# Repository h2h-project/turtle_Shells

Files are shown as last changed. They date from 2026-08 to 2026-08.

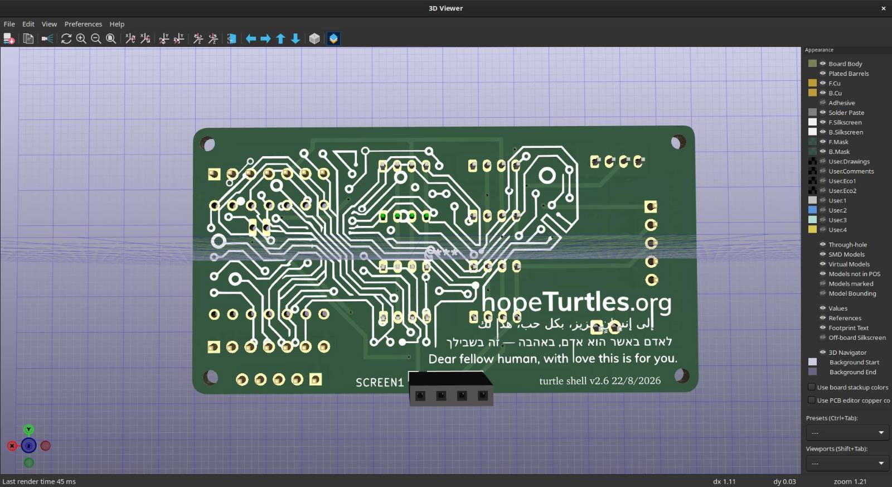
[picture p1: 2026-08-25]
photos/v2.6-back.jpg

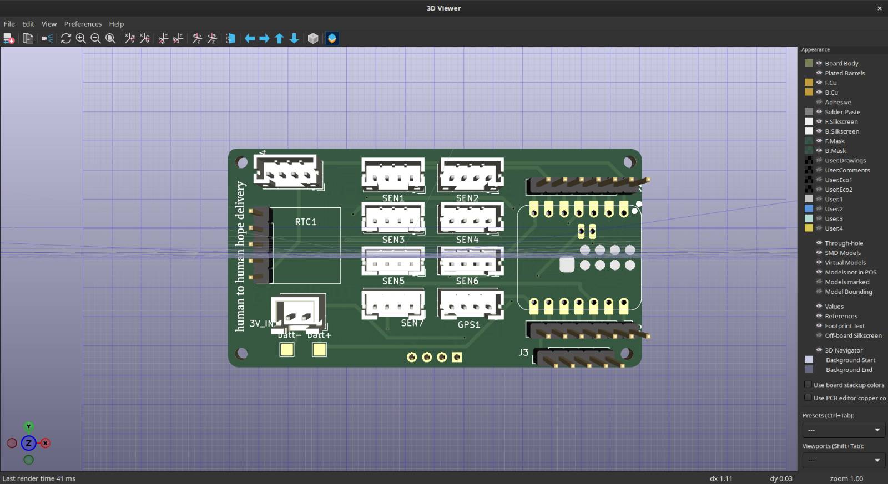
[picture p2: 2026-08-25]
photos/v2.6-front.png

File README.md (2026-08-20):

# The Hope Turtle Shell
### Our Open Source Printed Circuit Board for the Turtle Control Bottle

The Human2Human project aims to bring hope and humanity to the most hurting and isolated places on the planet — in a way that doesn't trouble the health and happiness of animals, fish and other our fellow creatures. To do so, we've developed the hope turtle: a non-capital, open-source, autonomous marine vehicle that embodies Earthen principles. This repository holds the designs for our "Turtle Shell" printed circuit board.  This is the PCB that holds of microprocessor, sensors and circuits to run our TurtleOS (https://github.com/h2h-project/turtleOS) navigation platform.  

Our vision is to create a simple and inexpensive PCB that anyone anywhere, keen to build a turtle, can put together themselves and set to sail for under 100$ using local and organic materials as much as possible.

## Philosophy

The design of our Turtle Shell PCB is shared under a CERN Open Hardware Licence Version 2 - Strongly Reciprocal.  While our CERN-OHL-S license does not legally restrict military use, we ask that anyone building on this work honor the spirit it was created in — this design exists to bring aid to isolated and vulnerable communities, not for weapons or warfare.  That's the same principle behind releasing this repository at all: any group doing resonant human/ecological work — coastal monitoring, disaster response, ocean research, humanitarian delivery — should be able to take this board, understand exactly how and why it's built the way it is, and carry it further without waiting on us or paying anyone for the privilege.

The Turtle Shell is designed from the ground up to be assembled by hand, by people who have never assembled a circuit board before. Every component on it is through-hole — there is no surface-mount soldering, no solder paste, no reflow oven, nothing that requires equipment beyond a basic iron and a steady hand. Sensors connect via inexpensive, widely-available modules and JST cables rather than being permanently fixed to the board, which keeps the parts list cheap, keeps a broken sensor a five-minute swap rather than a rework job, and keeps the barrier to building one of these low enough that a volunteer, a partner workshop, or a local maker space anywhere in the world can put one together. 

## The PCB

The current version of the Turtle Shell (v2.4) is a compact, two-layer, 70×37mm control board built around the Seeed Studio XIAO ESP32-S3.  While you don't necessarily need a Xiao ESP32-S3 to run turtle (turtleOS v2.3 has a hardware abstraction layer that supports only microprocessors), we've decided to focus our PCB development on this MP after extensively testing various alternatives.   While the Xiao ESP32-S3 is not nearly as equipped and robust as navigation specific boards, it resonates fully with our principles of open source and low-cost decentralized replicability.  The Xiao is also is a fraction of the cost-- which is crucial to our larger project goal of keeping turtle creation cost at under 100$.

The loaded turtle Shell essentially runs TurtleOS and coordinates everything the vessel does. It exposes seven generic 2.00mm JST sensor ports plus a dedicated GPS port, so the same board can carry whatever mix of instruments a given voyage needs — a magnetic angle encoder for rudder position, a combined accelerometer/gyroscope/compass/barometer for heading and weather, a current and voltage monitor for tracking the power budget, a temperature and humidity sensor to watch over the sealed enclosure's health — alongside dedicated sockets for a display and a real-time clock, breakout headers for the microcontroller's full pinout, and a servo connector kept deliberately isolated from the board's own power traces. It's a small board asked to do a lot, and every connector on it exists because a real sensor needed a reliable, correctly-oriented place to plug in.

Here's a quick list of our core components for our v.24 turtle shell:

| Component | Function | Interface | Approx. Cost (USD) |
|---|---|---|---|
| Seeed XIAO ESP32-S3 | Main microcontroller, runs TurtleOS | — | ~$7.50 |
| Xiao GPS module | Position & UTC time | UART, GPS1 port | ~$7 |
| GY-87 10DOF (MPU6050 + HMC5883L/QMC5883 + BMP180) | Heading, attitude, barometric pressure | I²C, SEN port | ~$7 |
| AS5600 | Rudder/servo angle sensing | I²C, SEN port | ~$1.50 |
| INA219 (GY-219) | Battery current, voltage & power monitoring | I²C, SEN port | ~$2 |
| AHT20 | Enclosure temperature & humidity | I²C, SEN port | ~$2.50 |
| 1.3" OLED (SH1106) | Status display | I²C, SCREEN1 socket | ~$4.50 |
| DS3231 RTC (5-pin) | Spoof-resistant, GPS-independent timekeeping | I²C, RTC1 header | ~$3.50 |
| JST↔Dupont cables (×6, mixed lengths) | Connect modules to SEN ports | — | ~$3 |
| **Subtotal** | | | **~$38** |

You can see an indepth breakdown of the Turtle hardware stack here:
https://github.com/h2h-project/turtleOS/blob/main/hardware_stack.md

## Where We're Headed

As of August 2026 we're in full development, printing and prototyping mode-- so things are evolving fast!  

The next revision is aimed at making the board more self-contained and more reliable at sea, without giving up the simplicity that makes it buildable by hand. We're working out how to bring battery power directly onto the board — using spring-loaded contacts to reach the microcontroller module's own charging circuit rather than routing through a less efficient path — alongside dedicated, correctly-keyed sockets for the current sensor and the inertial measurement unit, and a permanent home for the solar charging circuit, so fewer loose modules and wires are rattling around inside a hull that will spend weeks rolling in ocean swell. None of this is finished, and some of it may not survive contact with the next prototype — but the goal stays the same: a board that's a little more finished each time, still cheap, still imminently buildable, and still something anyone resonating with this repository and our human2human project can pick up and carry forward.

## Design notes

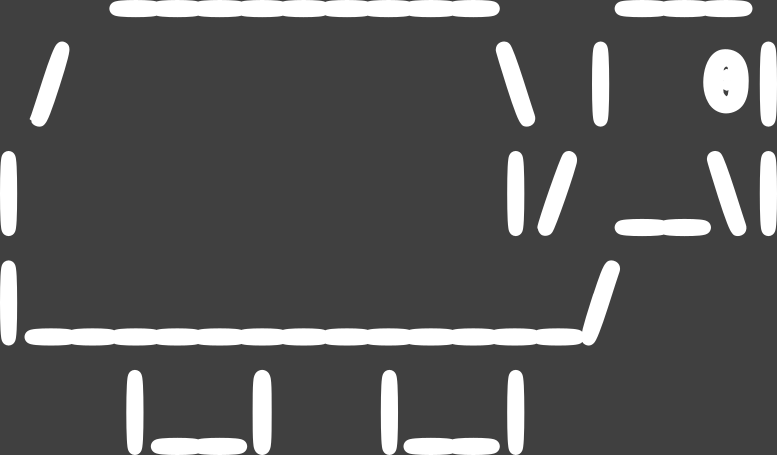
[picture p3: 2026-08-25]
pcb_art/ASCI_turtle.png

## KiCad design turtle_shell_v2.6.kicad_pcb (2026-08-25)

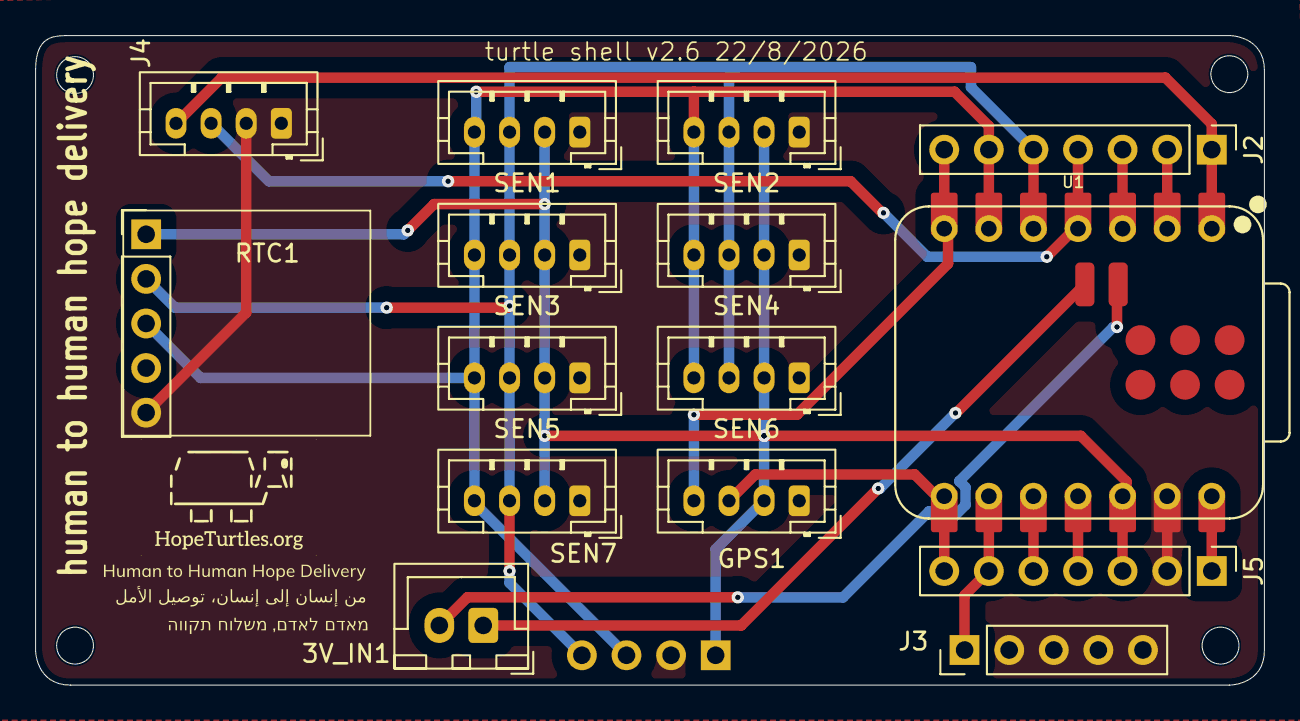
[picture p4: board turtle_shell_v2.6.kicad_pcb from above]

Board: 2 copper layers, 70.0 x 37.0 mm, 20 parts (1 on the bottom side), 16 nets.

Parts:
3V_IN1: 3v_in; JST_XH_B2B-XH-A_1x02_P2.50mm_Vertical
GPS1: gps; JST_PH_B4B-PH-K_1x04_P2.00mm_Vertical
H1, H2, H3, H4: MountingHole; MountingHole_2.1mm
J2, J5: 7 pin header; PinHeader_1x07_P2.54mm_Vertical
J3: servo gnd; PinHeader_1x05_P2.54mm_Vertical
J4: btn/led_con; JST_PH_B4B-PH-K_1x04_P2.00mm_Vertical
RTC1: RTC; PinHeader_1x05_P2.54mm_Vertical
SCREEN1: sensor; PinSocket_1x04_P2.54mm_Vertical
SEN1, SEN2, SEN3, SEN4, SEN5, SEN6, SEN7: sensor; JST_PH_B4B-PH-K_1x04_P2.00mm_Vertical
U1: XIAO-ESP32-C3-SMD; XIAO-ESP32-C3-DIP-SMD

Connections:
GND: GPS1.1, J3.2, J3.3, J3.4, J3.5, J4.1, J4.2, J5.2, RTC1.5, SCREEN1.2, SEN1.1, SEN2.1, SEN3.1, SEN4.1, SEN5.1, SEN6.1, SEN7.1, U1.13 (GND)
unnamed: 3V_IN1.1, U1.21 (VBAT)
unnamed: 3V_IN1.2, U1.22 (GND)
unnamed: GPS1.2, J5.3, RTC1.1, SCREEN1.1, SEN1.2, SEN2.2, SEN3.2, SEN4.2, SEN5.2, SEN6.2, SEN7.2, U1.12 (3V3_OUT)
unnamed: GPS1.3, J5.7, U1.8 (D7)
unnamed: GPS1.4, J2.7, U1.7 (D6)
unnamed: J2.1, J4.4, U1.1 (D0)
unnamed: J2.2, U1.2 (D1)
unnamed: J2.3, U1.3 (D2)
unnamed: J2.4, J4.3, U1.4 (D3)
unnamed: J2.5, RTC1.2, SCREEN1.4, SEN1.3, SEN2.3, SEN3.3, SEN4.3, SEN5.3, SEN6.3, SEN7.3, U1.5 (D4)
unnamed: J2.6, RTC1.3, SCREEN1.3, SEN1.4, SEN2.4, SEN3.4, SEN4.4, SEN5.4, SEN6.4, SEN7.4, U1.6 (D5)
unnamed: J3.1, J5.6, U1.9 (D8)
unnamed: J5.1, U1.14 (VBUS)
unnamed: J5.4, U1.11 (D10)
unnamed: J5.5, U1.10 (D9/BOOT)

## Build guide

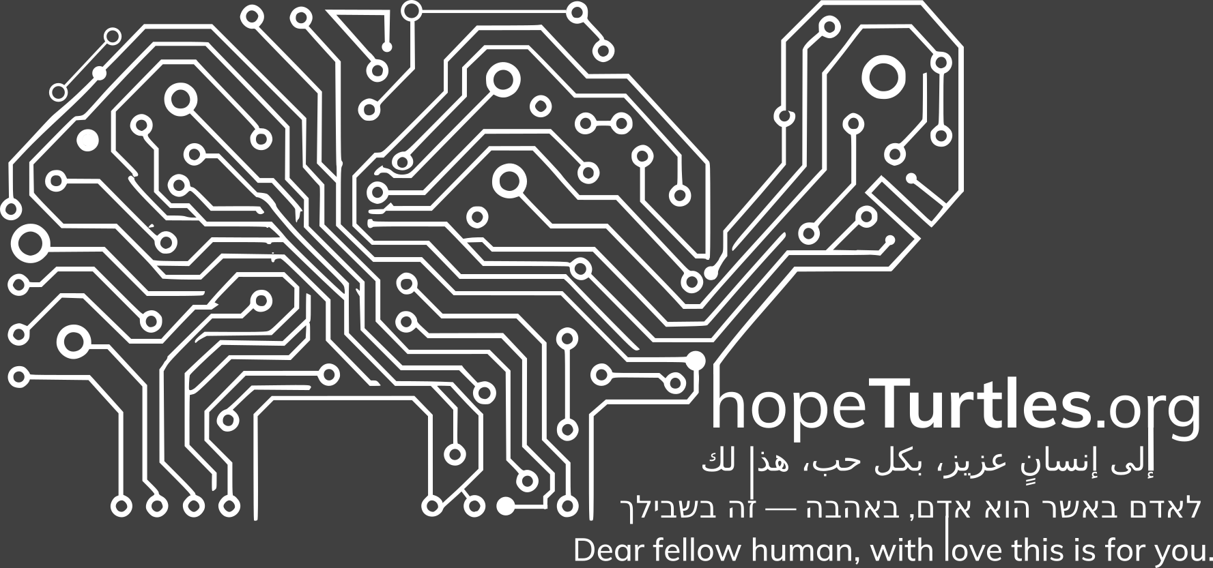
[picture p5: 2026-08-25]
pcb_art/Back_Full-turle-print.png
